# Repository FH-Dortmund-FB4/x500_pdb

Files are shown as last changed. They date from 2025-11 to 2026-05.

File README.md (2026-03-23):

# LM21305-Based Power Distribution Board
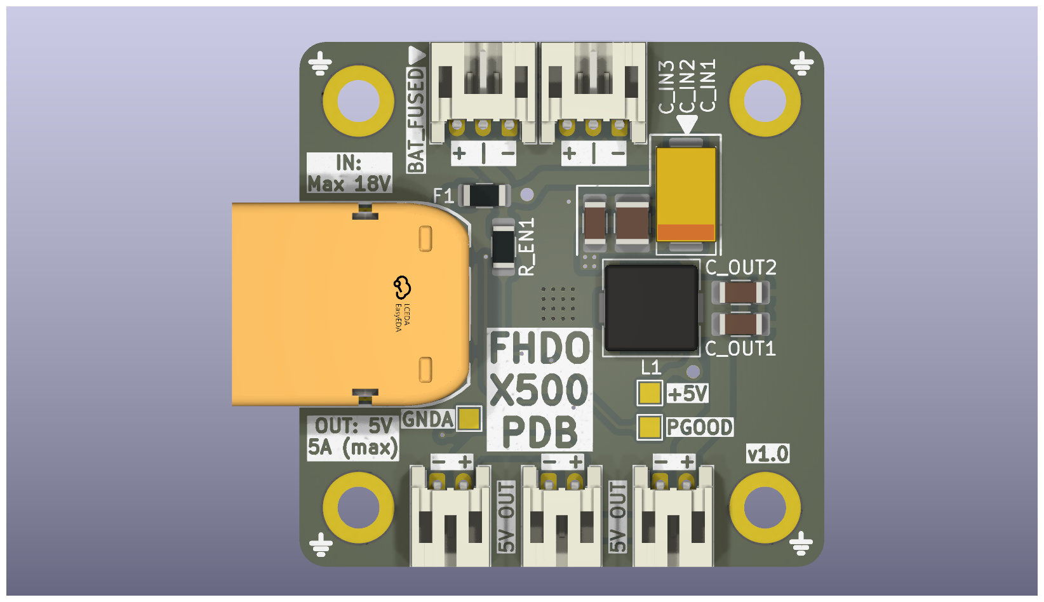
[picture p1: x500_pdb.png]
Board preview


## Overview

This project describes a compact power distribution board (PDB) for multicopter applications. The design is based on the LM21305 synchronous buck regulator and provides regulated 5 V outputs alongside direct battery connections.

The board follows a 30 × 30 mm mounting pattern, compatible with standard flight controller stacks.

## Features

- LM21305-based DC-DC regulation
- 30 × 30 mm mounting pattern
- Maximum output current: 5 A
- 3 × regulated 5 V outputs (JST-PH 2.0)
- 2 × battery outputs (JST-PH 2.0)

## Specifications

| Parameter | Value |
|---|---|
| Input Voltage | 3 V – 18 V |
| Regulated Output  | 5 V |
| Maximum Current | 5 A (total) |
| Mounting Pattern  | 30 × 30 mm |
| Connectors | JST-PH 2.0 |

## LM21305 Regulator Summary

The LM21305 is a synchronous step-down (buck) DC-DC converter with integrated power MOSFETs and peak current-mode control. :contentReference[oaicite:0]{index=0}  

Key characteristics:

- Input voltage range: 3 V to 18 V 
- Output current capability: up to 5 A 
- Adjustable switching frequency: 300 kHz to 1.5 MHz
- Integrated high-side and low-side MOSFETs 

Functional features:

- Peak current-mode control for fast transient response 
- Internal soft-start and enable control
- Cycle-by-cycle overcurrent protection and thermal shutdown
- Overvoltage and undervoltage protection

These characteristics enable high efficiency and compact external component selection.

## Electrical Interfaces

### 5 V Outputs (3×)
- 5 V
- Ground

### Battery Outputs (2×)
- VBAT
- Ground

## Mechanical Details

- Mounting hole spacing:  30 mm × 30 mm (M3 compatible)

## Contributions

Contributions and issue reports are welcome.

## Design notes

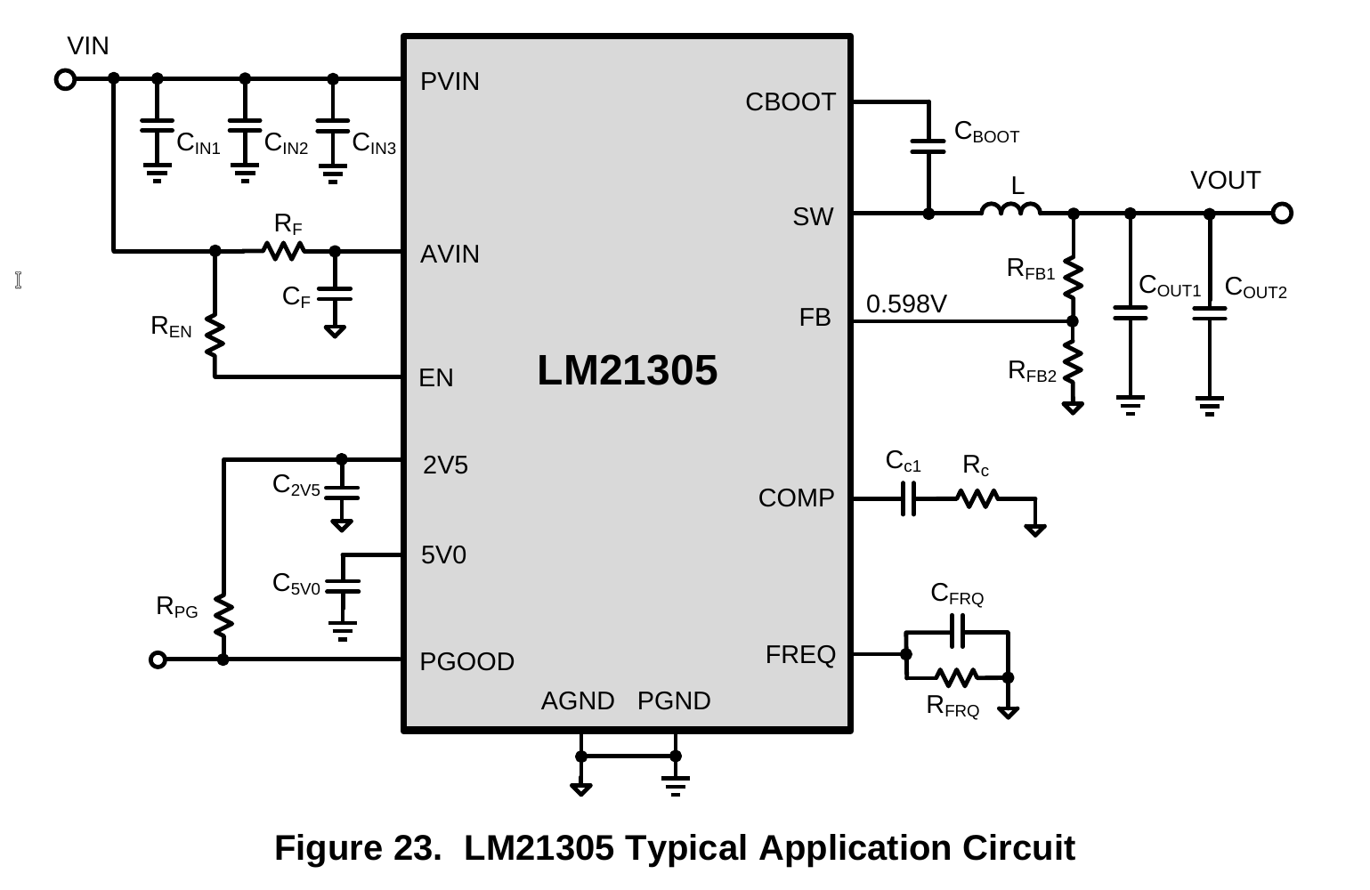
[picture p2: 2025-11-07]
Docs/typical_application.png

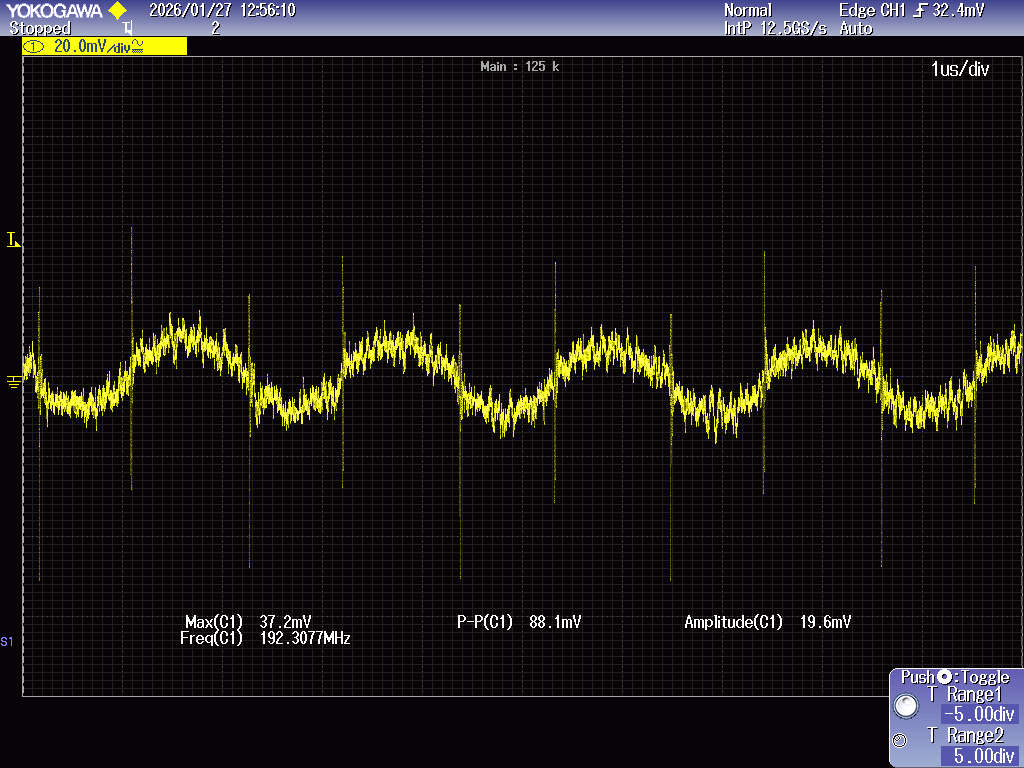
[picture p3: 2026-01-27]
Docs/1A.png

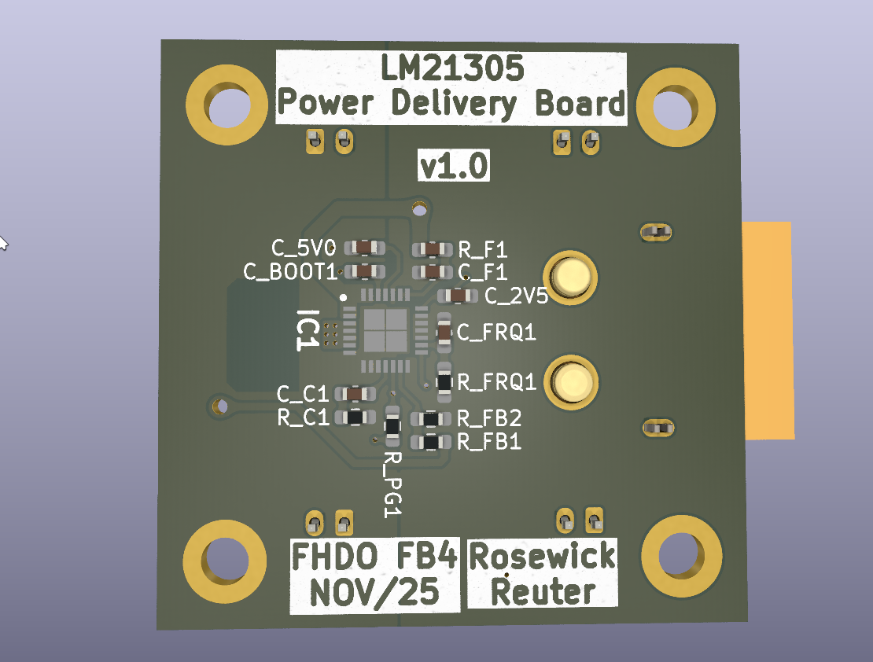
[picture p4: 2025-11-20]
Folder.png

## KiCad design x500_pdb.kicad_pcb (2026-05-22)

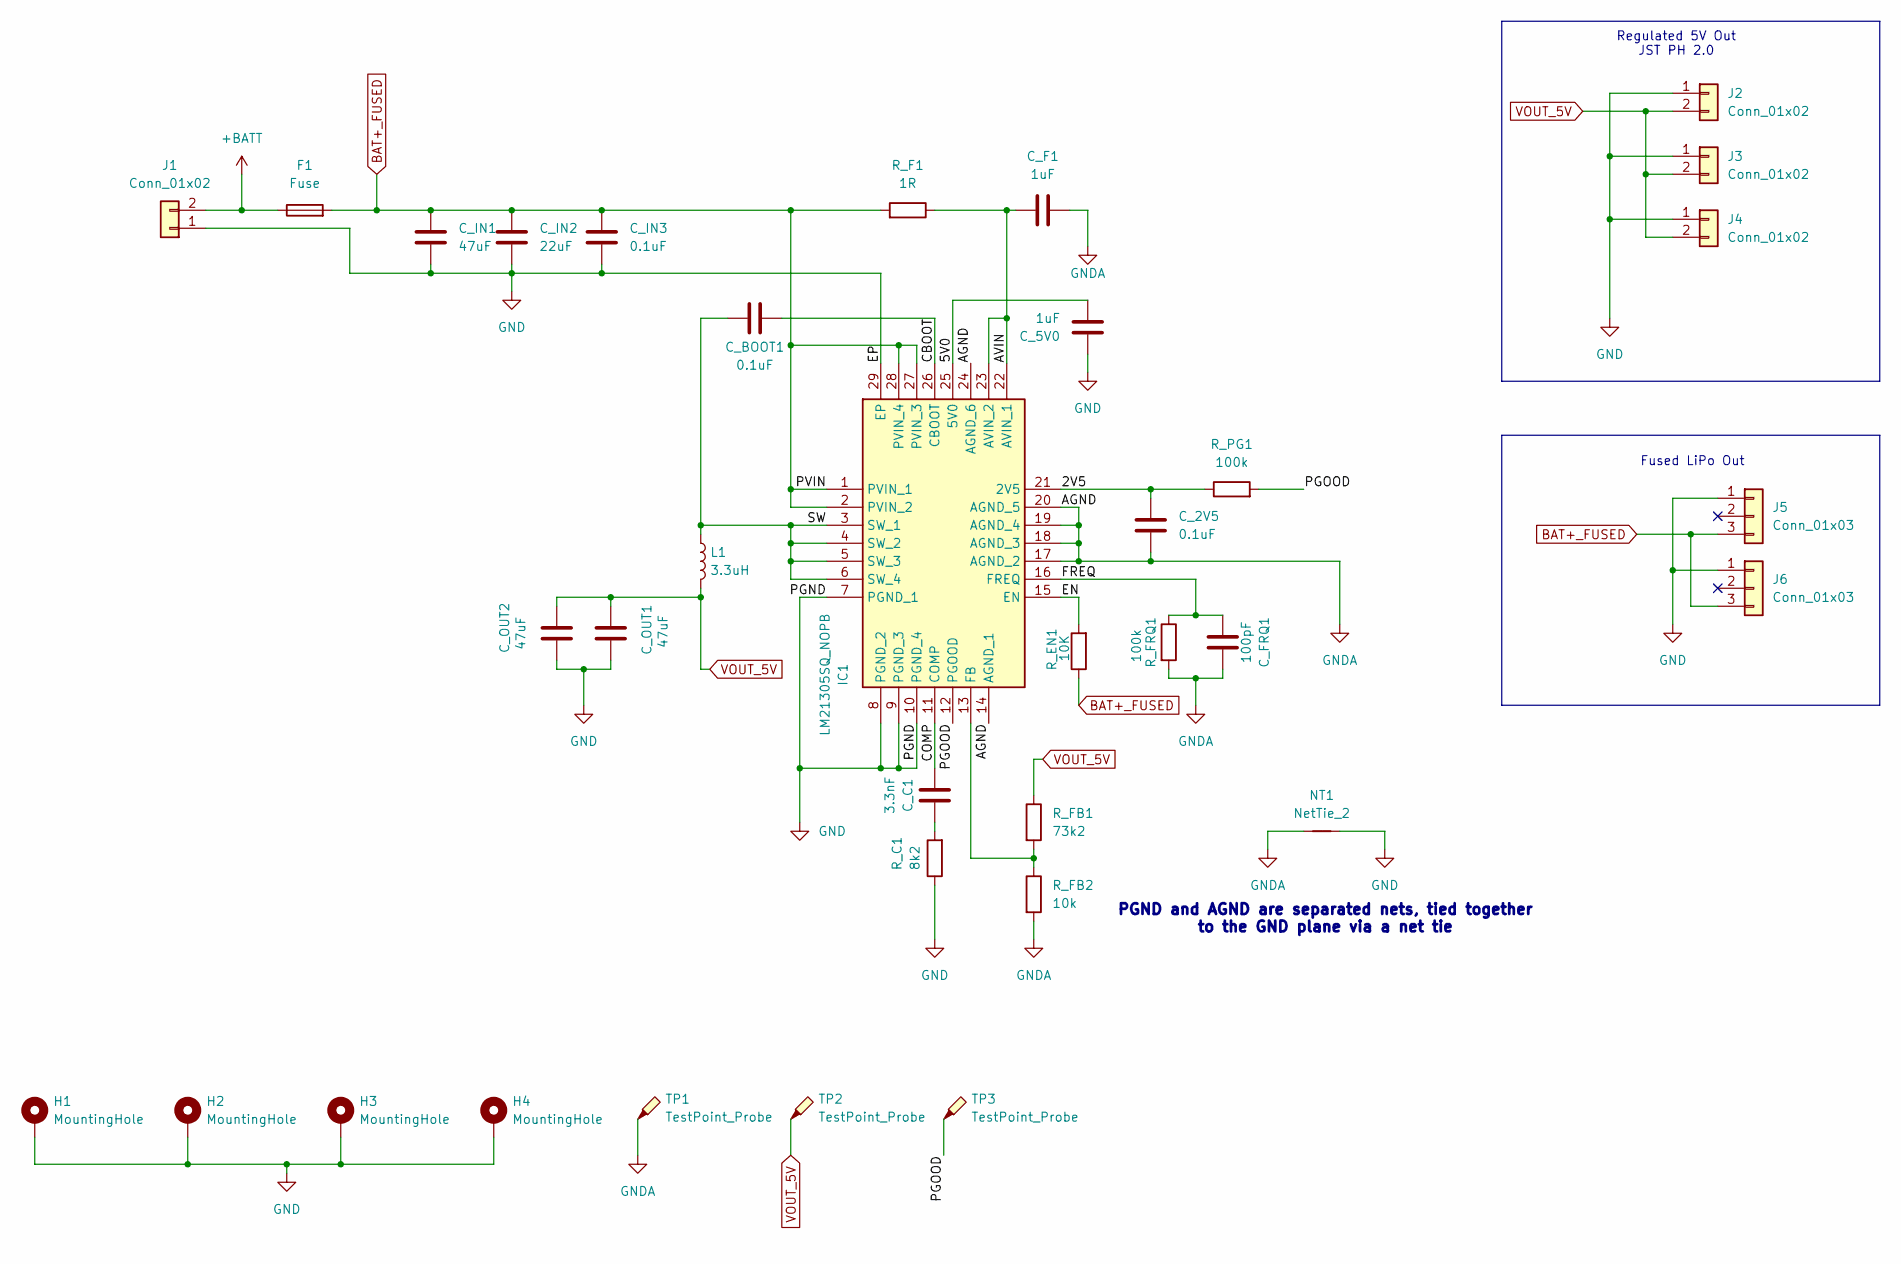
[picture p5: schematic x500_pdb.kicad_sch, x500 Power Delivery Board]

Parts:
C_2V5: 0.1uF; C_0603_1608Metric_Pad1.08x0.95mm_HandSolder; Mouser Part Number 80-C0603X104J4RECAUT
C_5V0: 1uF; C_0603_1608Metric_Pad1.08x0.95mm_HandSolder; Mouser Part Number 80-C0603X105J4R
C_BOOT1: 0.1uF; C_0603_1608Metric_Pad1.08x0.95mm_HandSolder; Mouser Part Number 80-C0603X104J4RECAUT
C_C1: 3.3nF; C_0603_1608Metric_Pad1.08x0.95mm_HandSolder; Mouser Part Number 581-0603YC332JAT2A
C_F1: 1uF; C_0603_1608Metric_Pad1.08x0.95mm_HandSolder; Mouser Part Number 187-CL10B105KA8NNWC
C_FRQ1: 100pF; C_0603_1608Metric_Pad1.08x0.95mm_HandSolder; Mouser Part Number 581-06033C101JAT4A
C_IN1: 47uF; CP_EIA-7343-20_Kemet-V_HandSolder; Mouser Part Number 80-T495D476K25ATE120
C_IN2: 22uF; C_1210_3225Metric_Pad1.33x2.70mm_HandSolder; Mouser Part Number 81-GRM32ER61E226KE15
C_IN3: 0.1uF; C_1206_3216Metric_Pad1.33x1.80mm_HandSolder; Mouser Part Number 81-GCJ31MR71E104KA1L
C_OUT1, C_OUT2: 47uF; C_1206_3216Metric_Pad1.33x1.80mm_HandSolder; Mouser Part Number 81-GRM31CR61A476KE5L
F1: Fuse; Fuse_1206_3216Metric; Mouser Part Number 652-SF-1206F250M-2
H1, H2, H3, H4: MountingHole; MountingHole_3.2mm_M3_DIN965_Pad_TopBottom
IC1: LM21305SQ_NOPB; QFN50P500X500X80-29N; Mouser Part Number 926-LM21305SQ/NOPB
J1: Conn_01x02; CONN-TH_XT60PW-M
J2, J3, J4: Conn_01x02; JST_PH_S2B-PH-K_1x02_P2.00mm_Horizontal; Mouser Part Number 306-S2BPHKSLFSNPP
J5, J6: Conn_01x03; JST_PH_S3B-PH-K_1x03_P2.00mm_Horizontal; Mouser Part Number 306-S3BPHKSLFSN
L1: 3.3uH; L_7.3x7.3_H3.5; Mouser Part Number 652-SRP7050WA-3R3M
NT1: NetTie_2; NetTie-2_SMD_Pad2.0mm
R_C1: 8k2; R_0603_1608Metric_Pad0.98x0.95mm_HandSolder; Mouser Part Number 652-CR0603FX-8201ELF
R_EN1: 10K; R_1206_3216Metric_Pad1.30x1.75mm_HandSolder; Mouser Part Number 756-WCR1206-10KFA
R_F1: 1R; C_0603_1608Metric_Pad1.08x0.95mm_HandSolder; Mouser Part Number 667-ERJ-3GEYJ1R0V
R_FB1: 73k2; R_0603_1608Metric_Pad0.98x0.95mm_HandSolder; Mouser Part Number 660-RN73H1JT7232F100
R_FB2: 10k; R_0603_1608Metric_Pad0.98x0.95mm_HandSolder; Mouser Part Number 71-CRCW060310K0FKEI
R_FRQ1: 100k; R_0603_1608Metric_Pad0.98x0.95mm_HandSolder; Mouser Part Number 594-MCT06030C1003FP5
R_PG1: 100k; R_0603_1608Metric_Pad0.98x0.95mm_HandSolder; Mouser Part Number 594-MCT06030C1003FP5
TP1, TP2, TP3: TestPoint_Probe; TestPoint_Pad_1.5x1.5mm

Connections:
+BATT: F1.1, J1.2
/2V5: C_2V5.1, IC1.21 (2V5), R_PG1.1
/5V0: C_5V0.2, IC1.25 (5V0)
/AVIN: C_F1.1, IC1.22 (AVIN_1), IC1.23 (AVIN_2), R_F1.1
/CBOOT: C_BOOT1.2, IC1.26 (CBOOT)
/COMP: C_C1.2, IC1.11 (COMP)
/EN: IC1.15 (EN), R_EN1.2
/FREQ: C_FRQ1.1, IC1.16 (FREQ), R_FRQ1.1
/PGOOD: IC1.12 (PGOOD), R_PG1.2, TP3.1
/SW: C_BOOT1.1, IC1.3 (SW_1), IC1.4 (SW_2), IC1.5 (SW_3), IC1.6 (SW_4), L1.1
BAT+_FUSED: C_IN1.1, C_IN2.1, C_IN3.1, F1.2, IC1.1 (PVIN_1), IC1.2 (PVIN_2), IC1.27 (PVIN_3), IC1.28 (PVIN_4), J5.3, J6.3, R_EN1.1, R_F1.2
GND: C_5V0.1, C_IN1.2, C_IN2.2, C_IN3.2, C_OUT1.1, C_OUT2.1, H1.1, H2.1, H3.1, H4.1, IC1.7 (PGND_1), IC1.8 (PGND_2), IC1.9 (PGND_3), IC1.10 (PGND_4), IC1.29 (EP), J1.1, J2.1, J3.1, J4.1, J5.1, J6.1, NT1.2, R_C1.1
GNDA: C_2V5.2, C_F1.2, C_FRQ1.2, IC1.14 (AGND_1), IC1.17 (AGND_2), IC1.18 (AGND_3), IC1.19 (AGND_4), IC1.20 (AGND_5), IC1.24 (AGND_6), NT1.1, R_FB2.2, R_FRQ1.2, TP1.1
unnamed: C_C1.1, R_C1.2
unnamed: IC1.13 (FB), R_FB1.2, R_FB2.1
VOUT_5V: C_OUT1.2, C_OUT2.2, J2.2, J3.2, J4.2, L1.2, R_FB1.1, TP2.1

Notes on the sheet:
Regulated 5V Out JST PH 2.0
Fused LiPo Out
PGND and AGND are separated nets, tied together to the GND plane via a net tie

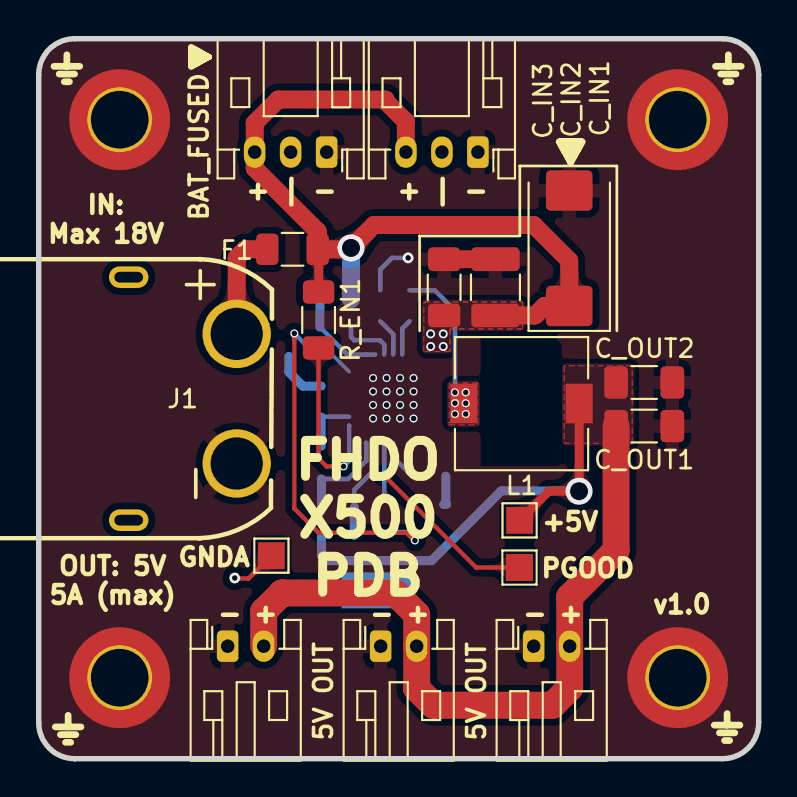
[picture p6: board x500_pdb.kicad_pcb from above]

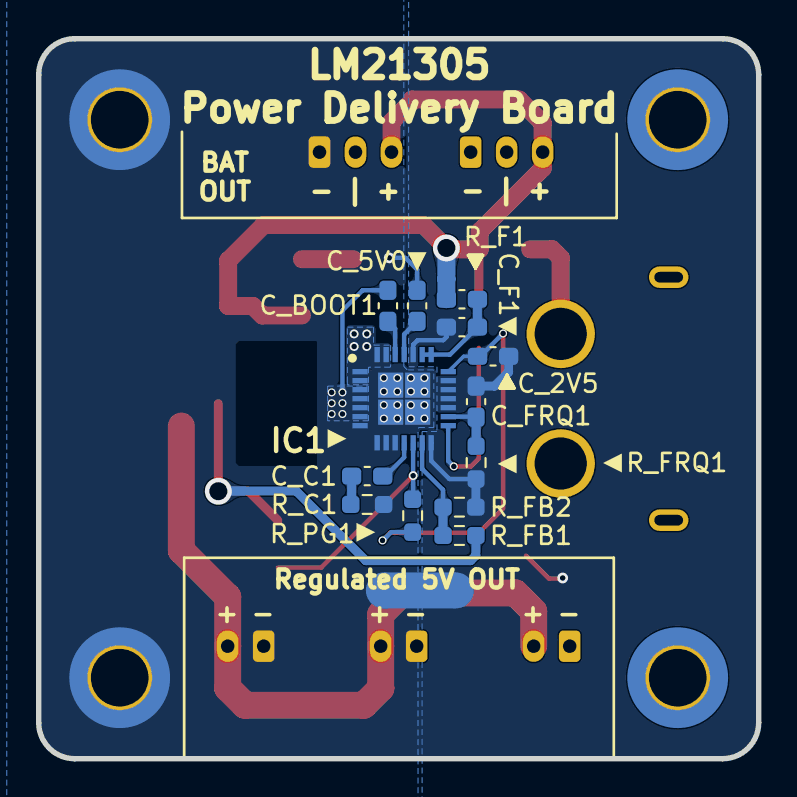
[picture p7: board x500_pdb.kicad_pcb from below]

Board: 4 copper layers, 40.0 x 40.0 mm, 35 parts (14 on the bottom side), 16 nets.

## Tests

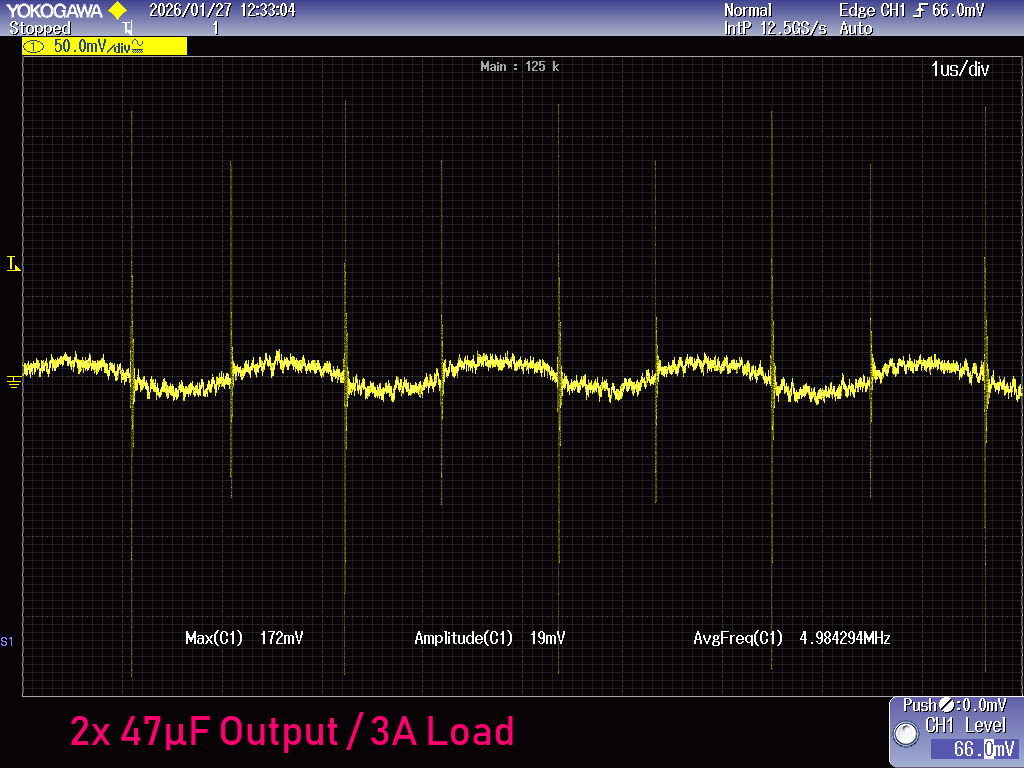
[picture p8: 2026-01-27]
Docs/measurement1.png

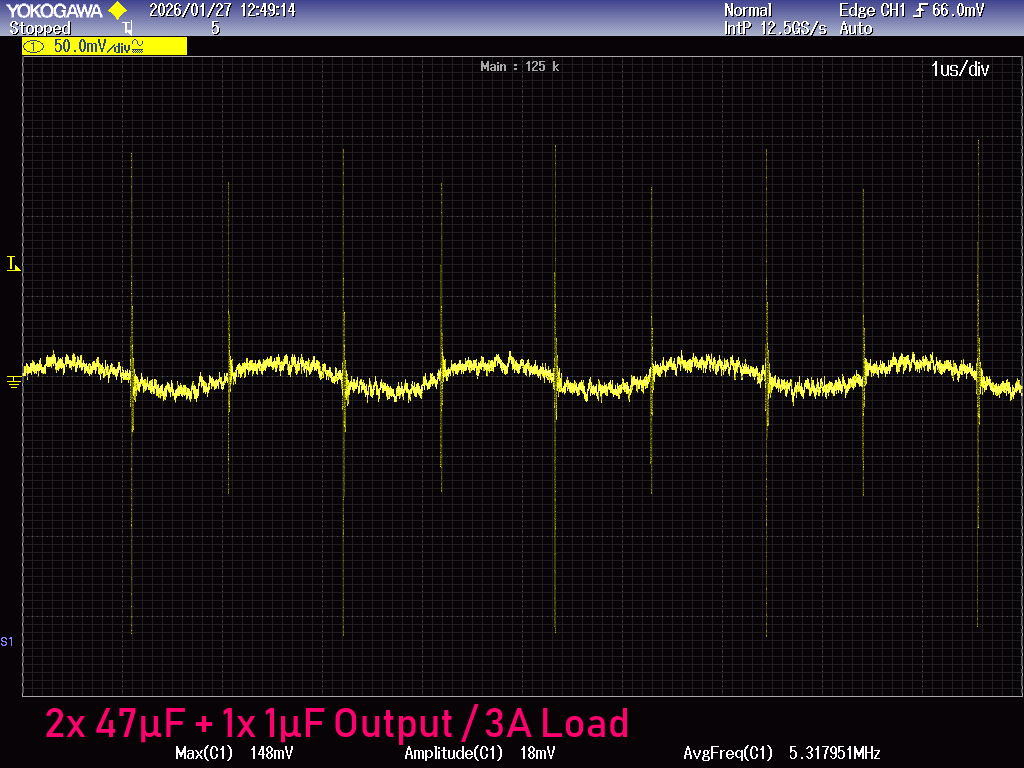
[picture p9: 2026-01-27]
Docs/measurement2.png

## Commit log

2025-11-07 4 Layers
    [x500_pdb.kicad_pcb, x500_pdb.kicad_sch]
2025-11-07 Started routing
    [x500_pdb.kicad_pcb]
2025-11-07 Prettying up schematics
    [x500_pdb.kicad_sch]
2025-11-18 Changing certain lines from +BATT to +BAT_FUSED
    [x500_pdb.kicad_sch]
2025-11-18 Updating PCB
    [x500_pdb.kicad_pcb]
2025-11-18 Add NetTie Footprint
    [x500_pdb.kicad_sch]
2025-11-18 Cleaning up GND split layer
    [x500_pdb.kicad_pcb]
2025-11-18 Clearing up violations
    [x500_pdb.kicad_pcb]
2025-11-18 Change mounting holes to plated ones
    [x500_pdb.kicad_sch]
2025-11-18 1.0-RC1. Need to move input caps closer
    [x500_pdb.kicad_pcb]
2025-11-20 1.0-RC2 Moving input caps close to IC, rearranging components
    [x500_pdb.kicad_pcb]
2025-11-20 1.0-RC2 Fixed Back Silkscreen
    [x500_pdb.kicad_pcb]
2025-11-26 Adding BAT_FUSED Outputs
    [x500_pdb.kicad_sch]
2025-11-26 1.0-RC3 Passing DRC
    [x500_pdb.kicad_pcb]
2025-12-02 1.0-RC3 Assigning Mouser Pt.No.
    [x500_pdb.kicad_pcb, x500_pdb.kicad_sch]
2025-12-03 Added Mouser Part-Numbers except XT60-Connector
    [x500_pdb.kicad_sch]
2026-02-13 Remove unused via and trace
    [x500_pdb.kicad_pcb]
2026-05-22 KiCad10.0 compatible Save
    [x500_pdb.kicad_pcb, x500_pdb.kicad_sch]
